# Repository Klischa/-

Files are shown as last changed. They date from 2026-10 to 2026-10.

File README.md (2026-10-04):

[README.md](https://github.com/user-attachments/files/33033183/README.md)
# Приводное / Опорно-ведущее колесо гусеницы «Муравей» z=24 (Шаг 50,5 мм)

Полный комплект конструкторской документации, файлов для ЧПУ резки и полноразмерных лекал (1:1) для приводной звездочки z=24 с трапециевидным зубом под гусеницу снегохода/буксировщика «Муравей».

---

## 1. Геометрические параметры венца z=24

- **Число зубьев ($z$):** 24
- **Шаг цевки ($p$):** 50,5 мм
- **Делительный диаметр ($d$):** 386,9 мм
- **Диаметр вершин ($d_a$):** 408,8 мм
- **Форма зуба:** Трапеция
  - Ширина плоской вершины: 6,97 мм
  - Радиусы скругления вершин: $R1,6 \pm 0,3$ мм
  - Угол наклона боковых граней (профиля): $20^\circ \pm 30'$
  - Радиус закругления впадин: $R3$ мм
- **Посадочные размеры ступицы (оригинал):**
  - Центральное отверстие: $\varnothing 75\text{ H7 } (+0,030)$ мм
  - Крепеж: 9 отверстий $\varnothing 9,5$ мм на диаметре $\varnothing 95$ мм (шаг $40^\circ$)
- **Толщина венца:** 10 мм
- **Материал:** СВМПЭ РЕ-1000 / Капролон ПА-6 / Сталь 09Г2С (толщина 10 мм)

---

## 2. Реализованные конструктивные решения

### Решение 1: Пакет с опорными боковыми катками (щеками)
- Звезда $z=24$ со стандартной высотой зуба ($d_f = 351,9$ мм, $h = 28,45$ мм).
- 2 опорные щеки $\varnothing 381,9$ мм толщиной по 19 мм (капролон / влагостойкая фанера ФСФ / Д16Т) с заходными фасками $3 \times 30^\circ$.
- Пакет стягивается 9 болтами М8×65. Общая ширина пакета **48 мм** (под 50-мм коридор клыков гусеницы «Муравей» с зазором по 1 мм на сторону).
- Скобы гусеницы опираются на гладкие щеки $\varnothing 381,9$ мм, исключая вибрацию и проваливание.

### Решение 2: Звездочка с опорным дном впадин ($d_f = 378,4$ мм)
- Одиночная звезда толщиной 10 мм без дополнительных катков.
- Дно впадины поднято до $d_f = 378,4$ мм ($h = 15,2$ мм), благодаря чему скобы гусеницы мягко ложатся на дно впадин.

---

## 3. Структура репозитория

```
├── README.md                                # Техническое описание проекта
├── drawings/                                # Конструкторские чертежи (ЕСКД/ГОСТ)
│   ├── sprocket_z24_support_drawing_A4.pdf  # Опорная звезда df=378.4 (1 лист А4)
│   ├── sprocket_z24_standard_drawing_A4.pdf # Приводная звезда df=351.9 (1 лист А4)
│   ├── cheek_d382_drawing_A4.pdf            # Щека опорная Ø381.9 (1 лист А4)
│   ├── assembly_wheel_drawing_A4.pdf        # Сборочный чертеж пакета 48 мм (1 лист А4)
│   └── all_four_a4_drawings_compiled.pdf    # Все 4 чертежа в едином файле для печати
├── cnc_dxf/                                 # Векторные чертежи для станков ЧПУ
│   ├── sprocket_z24_support_df378.dxf       # Контур опорной звезды df=378.4
│   ├── cheek_roller_d382.dxf                # Контур щеки Ø381.9
│   └── sprocket_muravey_z24_trapezoid.dxf   # Контур стандартной звезды df=351.9
├── templates_1to1/                          # Шаблоны 1:1 для распечатки и контроля
│   ├── sprocket_z24_support_sector_1to1.pdf # Сектор 6 зубьев df=378.4 на 1 лист А4
│   ├── sprocket_z24_support_1to1_tiled.pdf  # Полная звезда df=378.4 (7 листов А4)
│   ├── cheek_roller_d382_sector_1to1.pdf    # Сектор щеки Ø381.9 на 1 лист А4
│   └── sprocket_z24_sector_1to1.pdf         # Сектор стандартной звезды на 1 лист А4
└── scripts/                                 # Скрипты генерации геометрии (Python)
    └── render_complete_set_a4.py
```

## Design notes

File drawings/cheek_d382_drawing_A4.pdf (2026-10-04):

Б-Б (1:4)

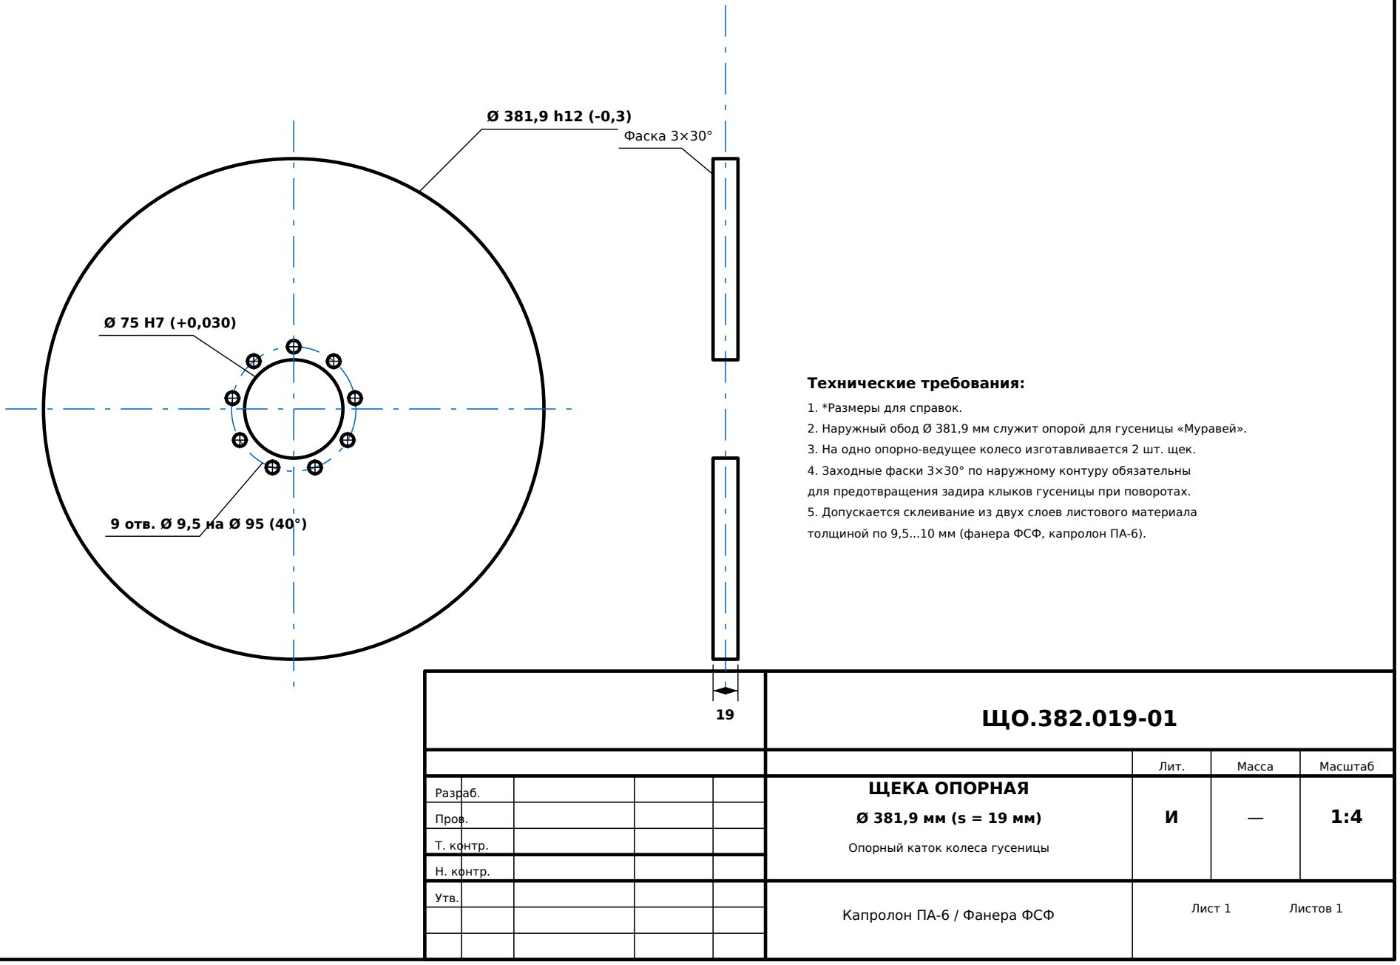
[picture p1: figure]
ЩЕКА ОПОРНАЯ; Опорный каток колеса гусеницы; Капролон ПА-6 / Фанера ФСФ; Лит.; Масса; Масштаб; Лист 1; Листов 1; Разраб.; Пров.; Т. контр.; Н. контр.; Утв.; 9 отв. Ø 9,5 на Ø 95 (40°); Фаска 3×30°; Технические требования:; 1. *Размеры для справок.

2. Наружный обод Ø 381,9 мм служит опорой для гусеницы «Муравей».
3. На одно опорно-ведущее колесо изготавливается 2 шт. щек.
4. Заходные фаски 3×30° по наружному контуру обязательны
для предотвращения задира клыков гусеницы при поворотах.
5. Допускается склеивание из двух слоев листового материала толщиной по 9,5...10 мм (фанера ФСФ, капролон ПА-6).

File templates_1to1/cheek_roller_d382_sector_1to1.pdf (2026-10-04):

# ШАБЛОН-СЕКТОР БОКОВОЙ ОПОРНОЙ ЩЕКИ Ø 381.9 мм — 1:1

## Опорный каток под резиновую дорожку гусеницы «Муравей» (2 шт. на 1 колесо, толщина 19 мм)

ЦЕНТР ЩЕКИ (0,0)

ЛУЧ 60° (ЛИНИЯ РАЗМЕТКИ) | ЛУЧ 60°

## НАРУЖНЫЙ ОПОРНЫЙ ОБОД Ø 381.9 мм (ПОД ПОЛОТНО ГУСЕНИЦЫ)

## КАК ИЗГОТОВИТЬ ОПОРНУЮ ЩЕКУ ПО ДАННОМУ ШАБЛОНУ:

- Требуется 2 щеки на одно колесо. Толщина каждой щеки 18...19 мм (или склеить из двух слоев по 9.5-10 мм).
- Разметка: закрепить центр (0,0) в заготовке, очертить дугу 60°, повернуть 6 раз -> замкнутый круг Ø381.9 мм.
- Просверлить центр Ø 75 мм и 9 отверстий Ø 9.5 мм на Ø 95 мм (совпадают со звездой).
- По наружной кромке снять фаску 3×30° для легкого центрирования между клыками гусеницы.
0 мм | 10 | 20 | 30 | 40 | 50 | 60 | 70 | 80 | 90 | 100

КОНТРОЛЬНАЯ ШКАЛА 100 мм (ПРОВЕРКА МАСШТАБА 1:1)

Масштаб 1:1 (100%)

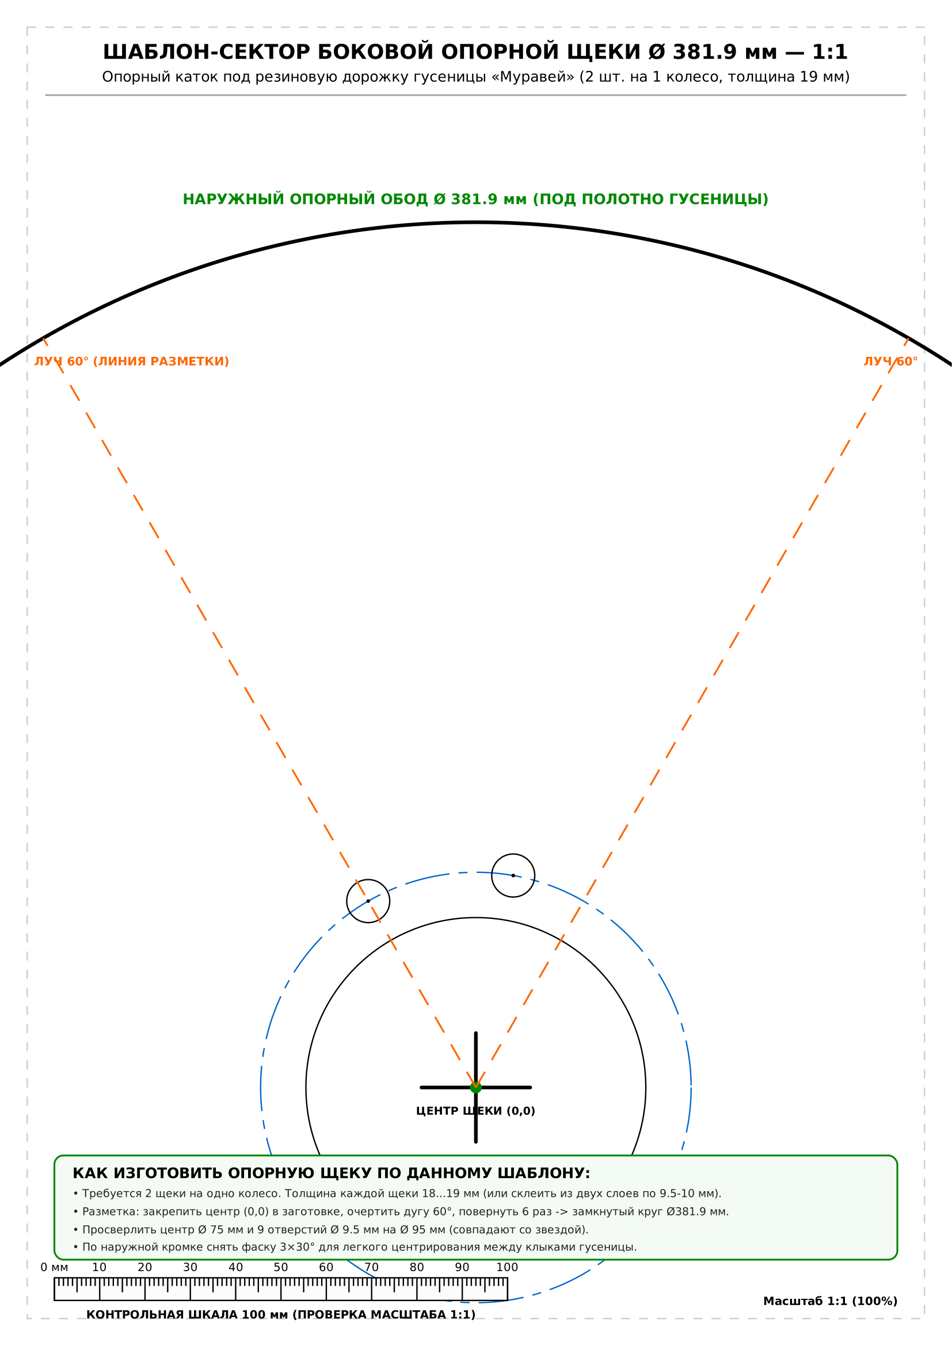
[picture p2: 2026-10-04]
templates_1to1/cheek_roller_d382_sector_1to1.png

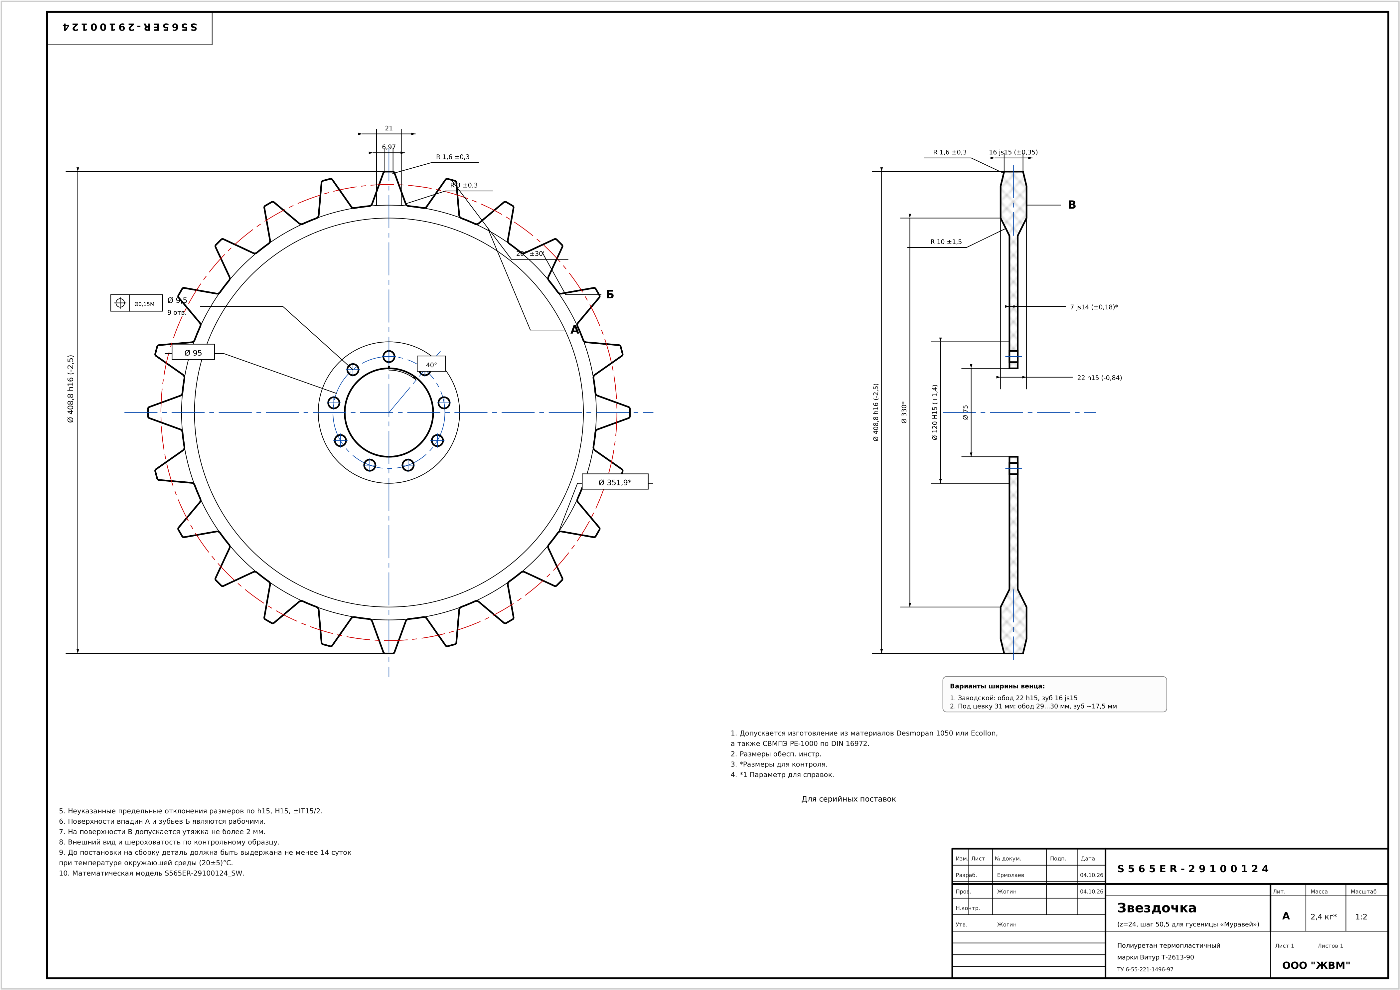
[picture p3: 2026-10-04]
drawings/sprocket_z24_support_df378.png

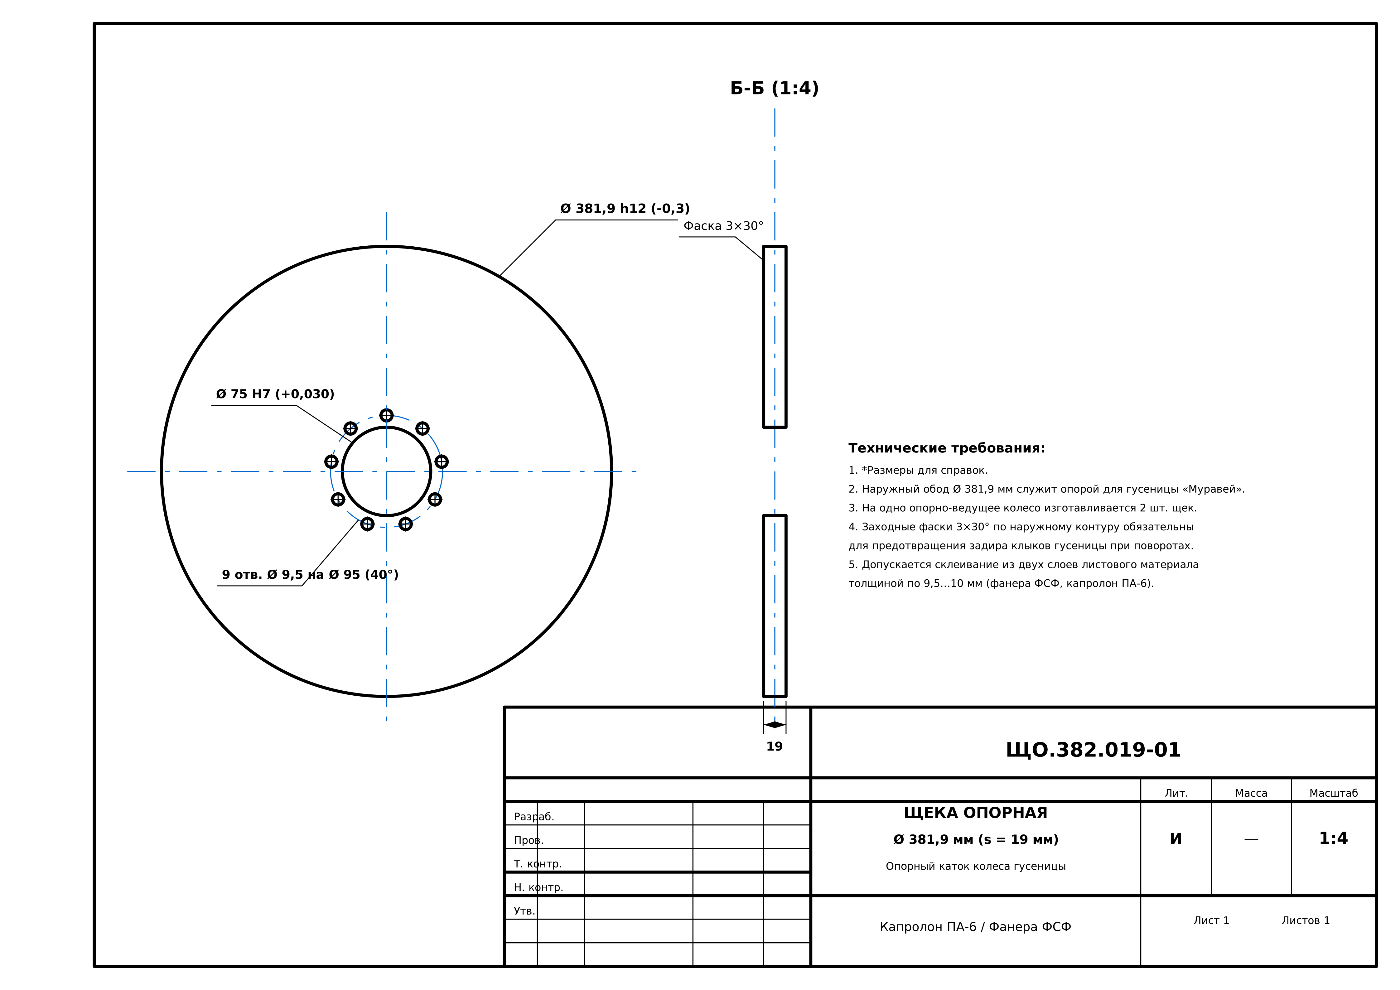
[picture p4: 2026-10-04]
drawings/cheek_d382_drawing_A4.png

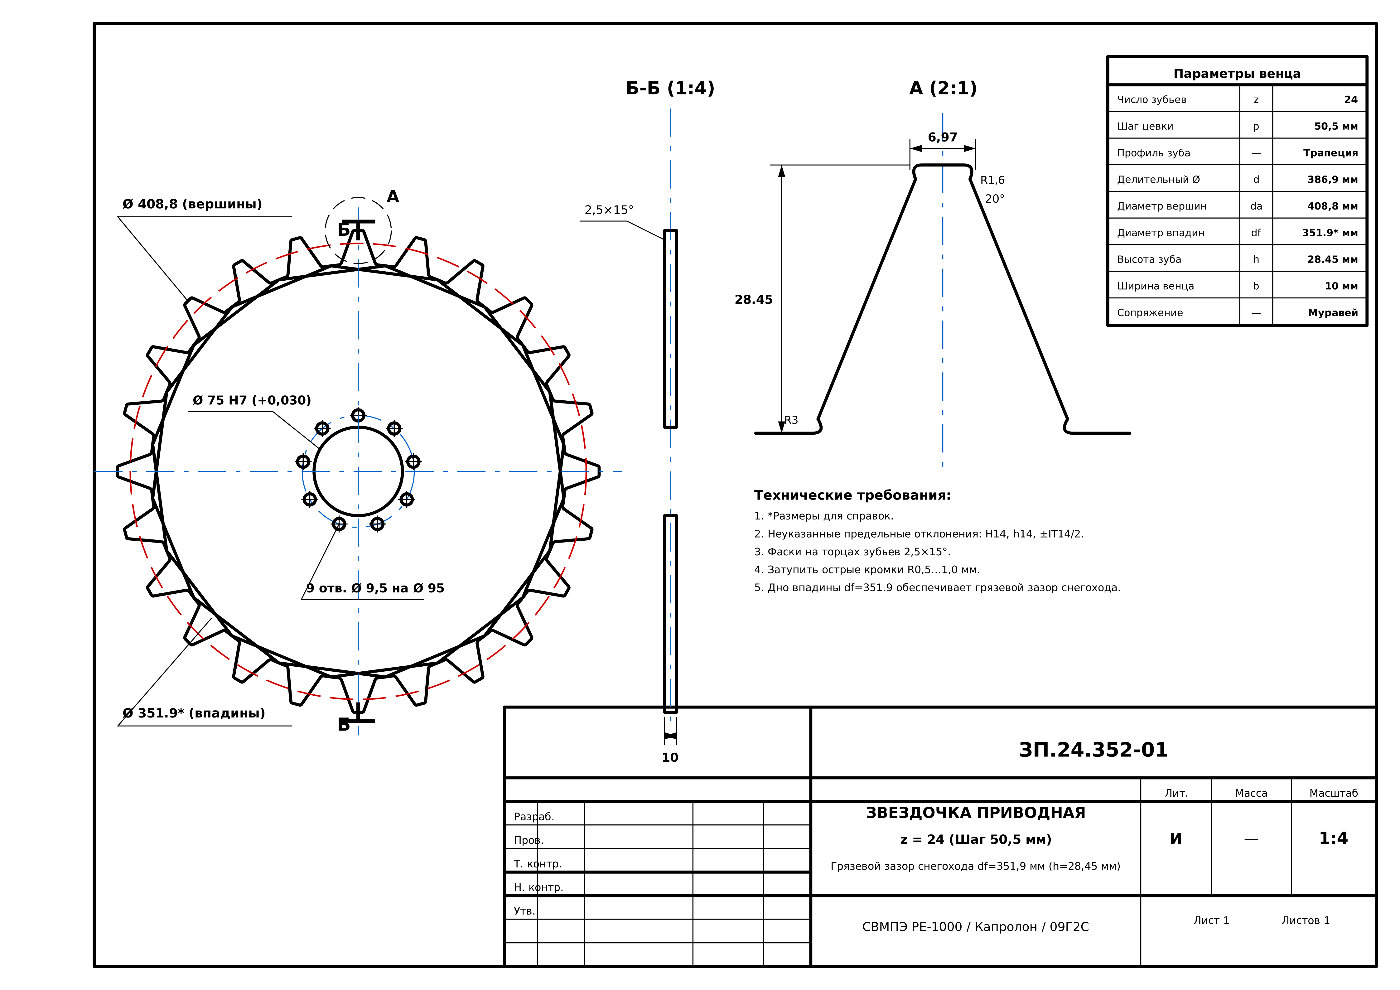
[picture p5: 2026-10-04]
drawings/sprocket_z24_standard_drawing_A4.png

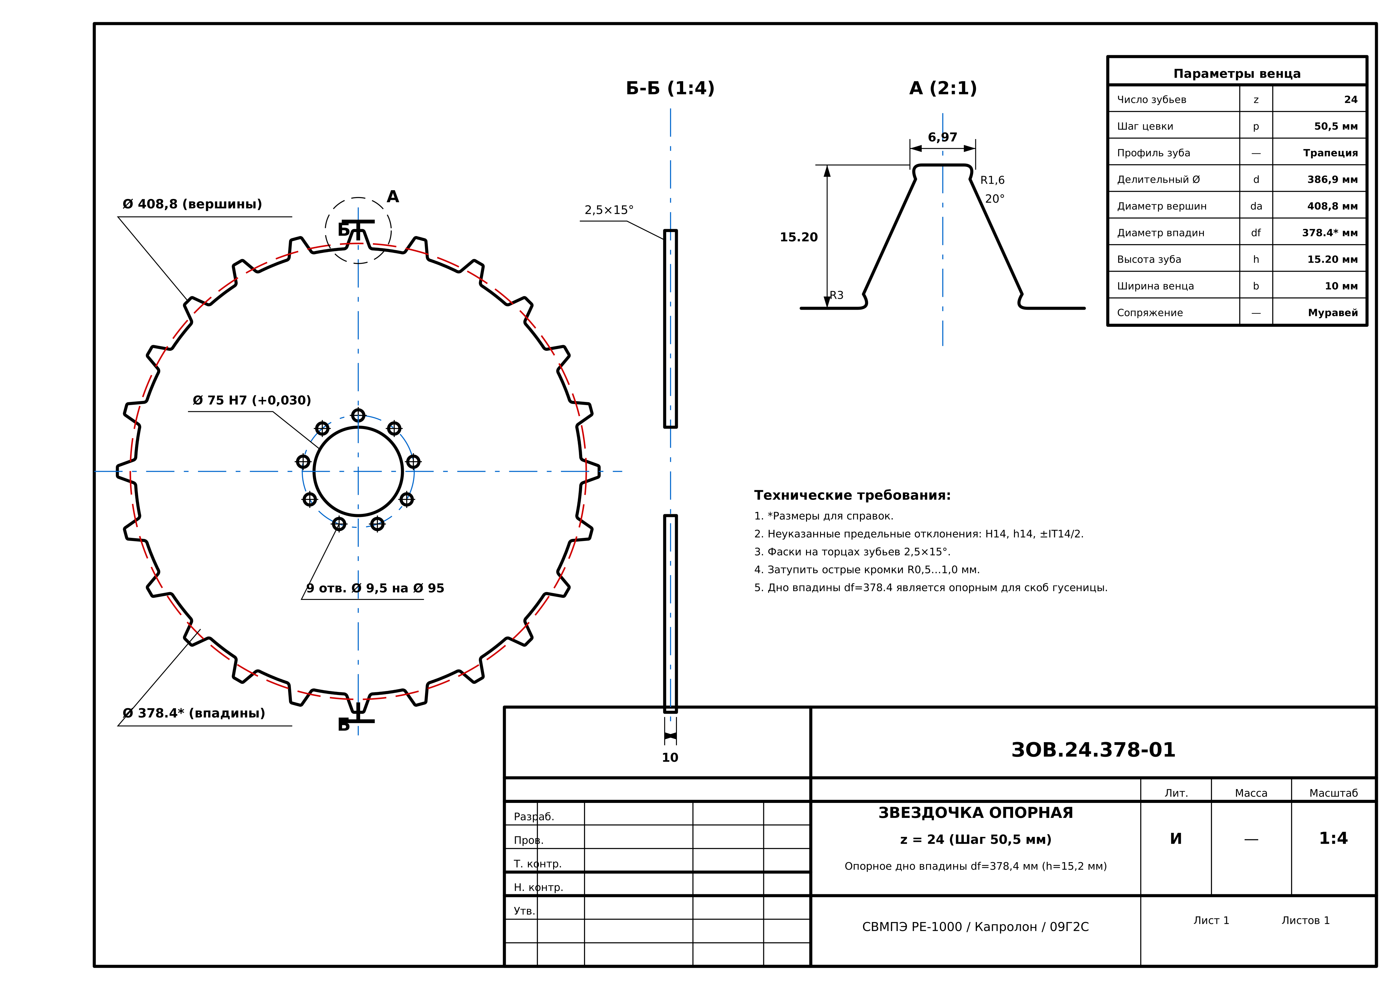
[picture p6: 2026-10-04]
drawings/sprocket_z24_support_drawing_A4.png

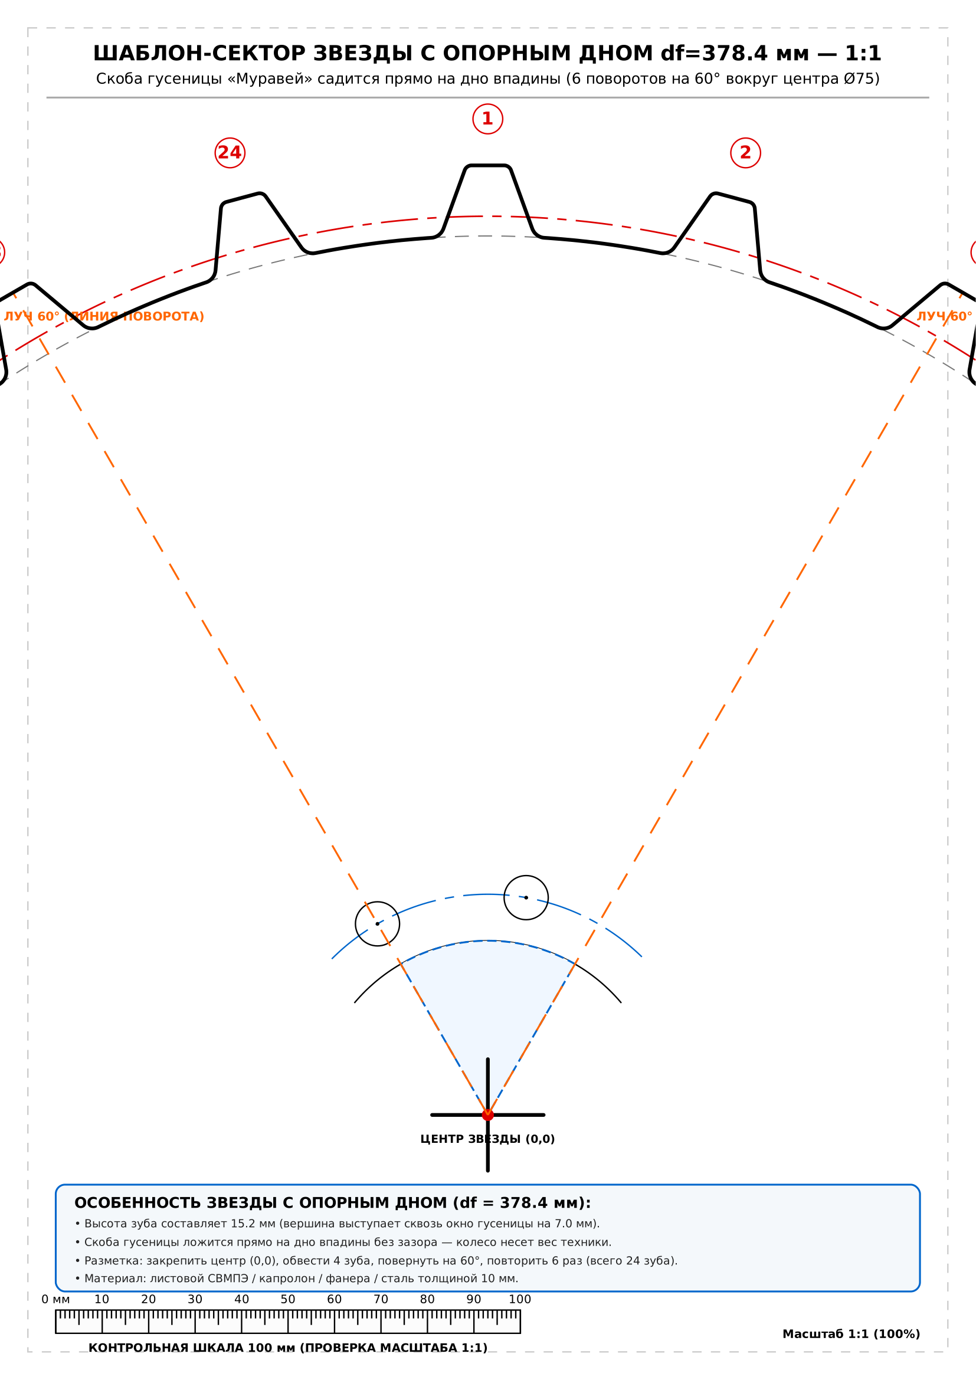
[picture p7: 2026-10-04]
templates_1to1/sprocket_z24_support_sector_1to1.png

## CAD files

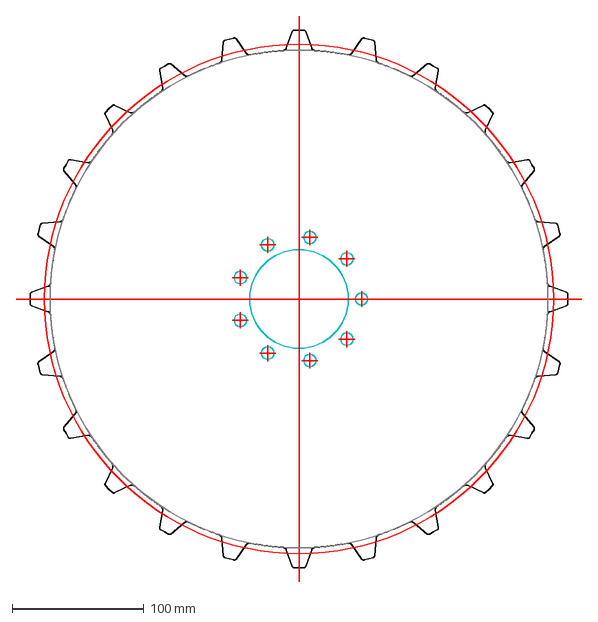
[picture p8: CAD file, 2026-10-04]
cnc_dxf/sprocket_z24_support_df378.dxf
430.0 x 430.0 mm

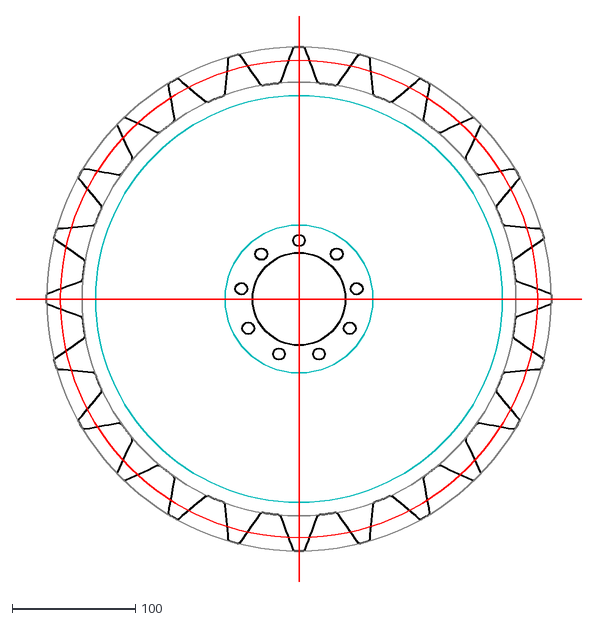
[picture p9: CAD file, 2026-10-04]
cnc_dxf/sprocket_muravey_z24_trapezoid.dxf
458.8 x 458.8

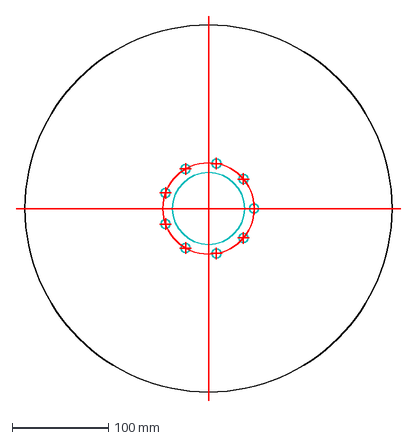
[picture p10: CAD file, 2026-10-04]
cnc_dxf/cheek_roller_d382.dxf
400.0 x 400.0 mm

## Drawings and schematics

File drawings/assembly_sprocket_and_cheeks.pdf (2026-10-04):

0

20

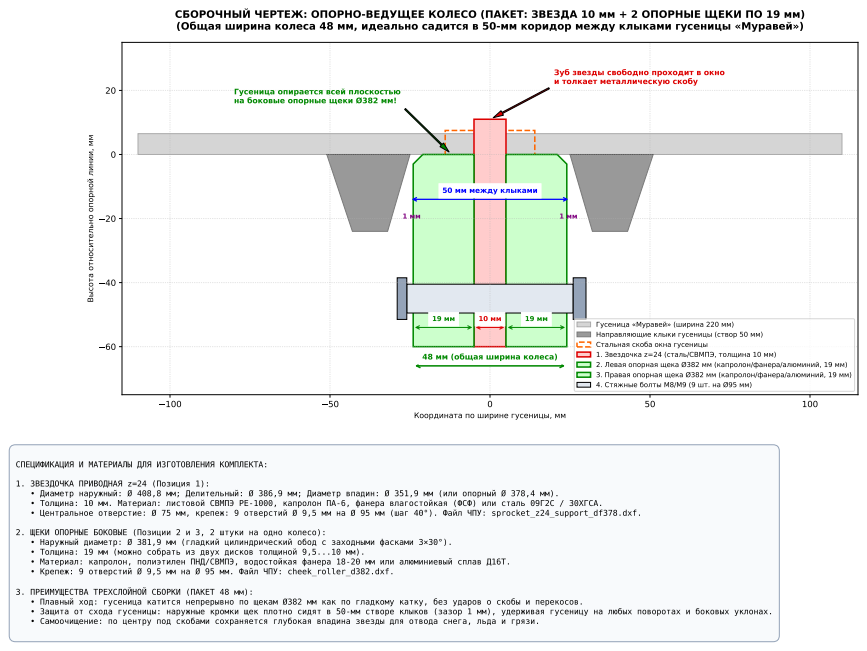
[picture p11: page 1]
: sprocket_z24_support_df378.dxf.; : cheek_roller_d382.dxf.

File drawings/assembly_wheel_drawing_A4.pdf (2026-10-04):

1
2

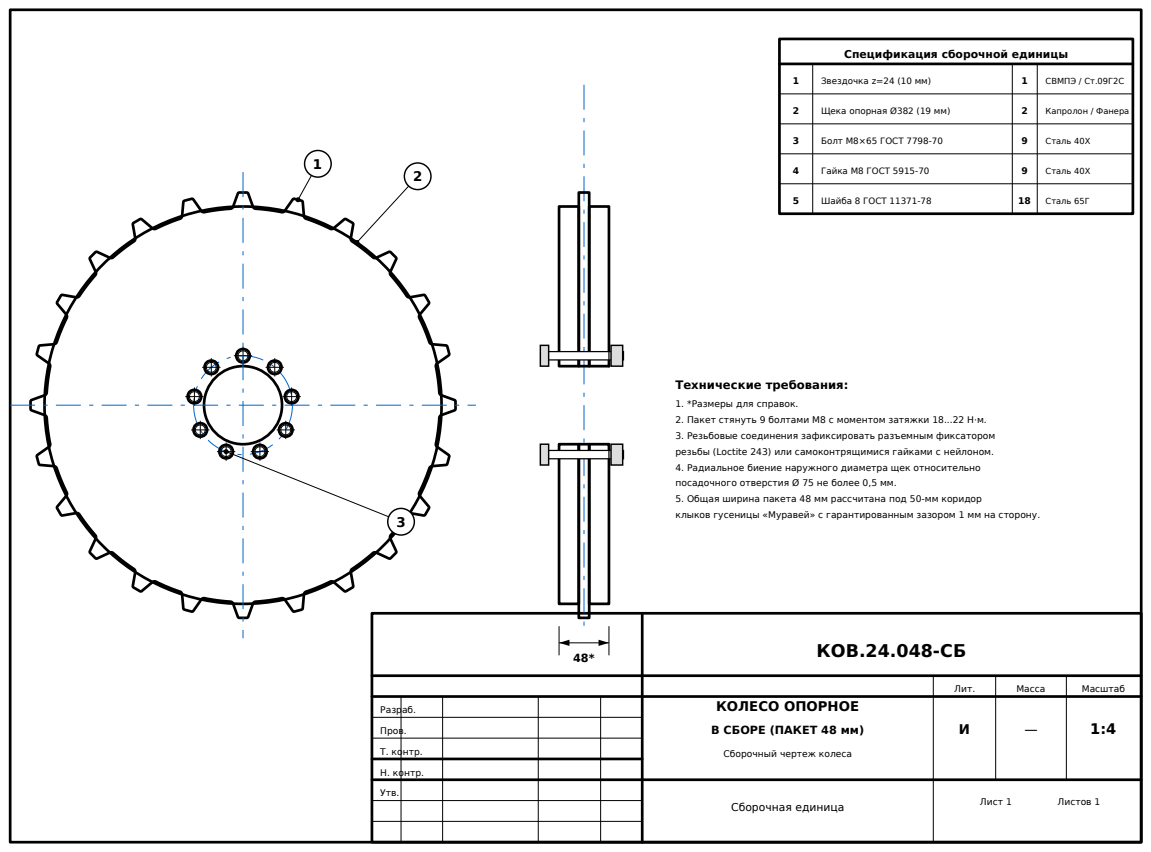
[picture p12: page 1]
КОВ.24.048-СБ; Сборочная единица; Лит.; Масса; Масштаб; Лист 1; Листов 1; Разраб.; Пров.; Т. контр.; Н. контр.; Утв.; Звездочка z=24 (10 мм); СВМПЭ / Ст.09Г2С; Щека опорная Ø382 (19 мм); Капролон / Фанера; Болт М8×65 ГОСТ 7798-70; Сталь 40Х; Гайка М8 ГОСТ 5915-70; Шайба 8 ГОСТ 11371-78; Сталь 65Г; Технические требования:

Спецификация сборочной единицы

1. *Размеры для справок.
2. Пакет стянуть 9 болтами М8 с моментом затяжки 18...22 Н·м.
3. Резьбовые соединения зафиксировать разъемным фиксатором
резьбы (Loctite 243) или самоконтрящимися гайками с нейлоном.
4. Радиальное биение наружного диаметра щек относительно
посадочного отверстия Ø 75 не более 0,5 мм.
5. Общая ширина пакета 48 мм рассчитана под 50-мм коридор
клыков гусеницы «Муравей» с гарантированным зазором 1 мм на сторону.

КОЛЕСО ОПОРНОЕ
В СБОРЕ (ПАКЕТ 48 мм)

Сборочный чертеж колеса

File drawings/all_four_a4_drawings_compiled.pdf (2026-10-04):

A
Б

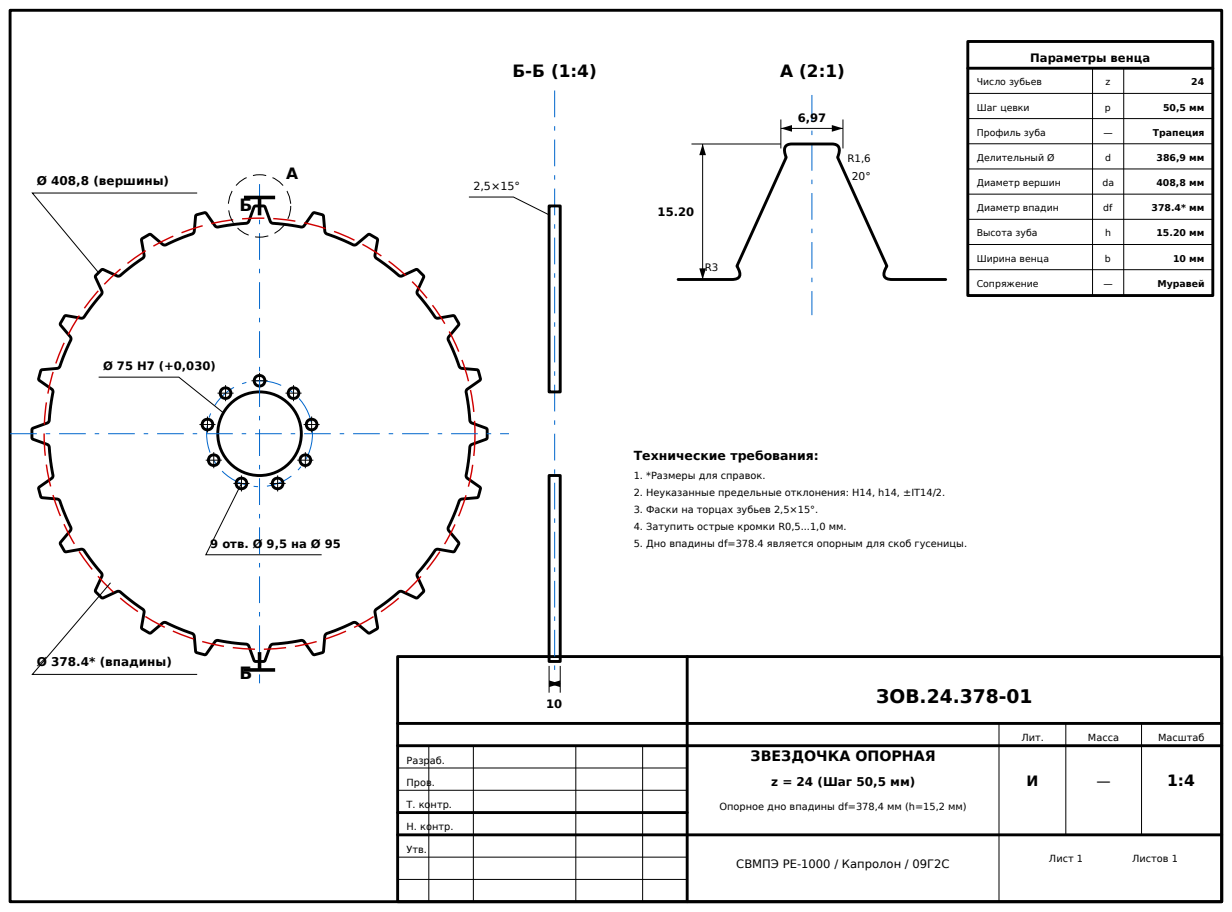
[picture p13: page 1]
ЗОВ.24.378-01; ЗВЕЗДОЧКА ОПОРНАЯ; z = 24 (Шаг 50,5 мм); Лит.; Масса; Масштаб; Лист 1; Листов 1; Разраб.; Пров.; Т. контр.; Н. контр.; Утв.; Ø 408,8 (вершины); Ø 378.4* (впадины); 9 отв. Ø 9,5 на Ø 95; Параметры венца; Число зубьев; Шаг цевки; Профиль зуба; Трапеция; Делительный Ø; Диаметр вершин; Диаметр впадин; Высота зуба; Ширина венца; Сопряжение; Муравей

Технические требования:
1. *Размеры для справок.
2. Неуказанные предельные отклонения: H14, h14, ±IT14/2.
3. Фаски на торцах зубьев 2,5×15°.
4. Затупить острые кромки R0,5...1,0 мм.
5. Дно впадины df=378.4 является опорным для скоб гусеницы.

Опорное дно впадины df=378,4 мм (h=15,2 мм)

СВМПЭ РЕ-1000 / Капролон / 09Г2С

A
Б

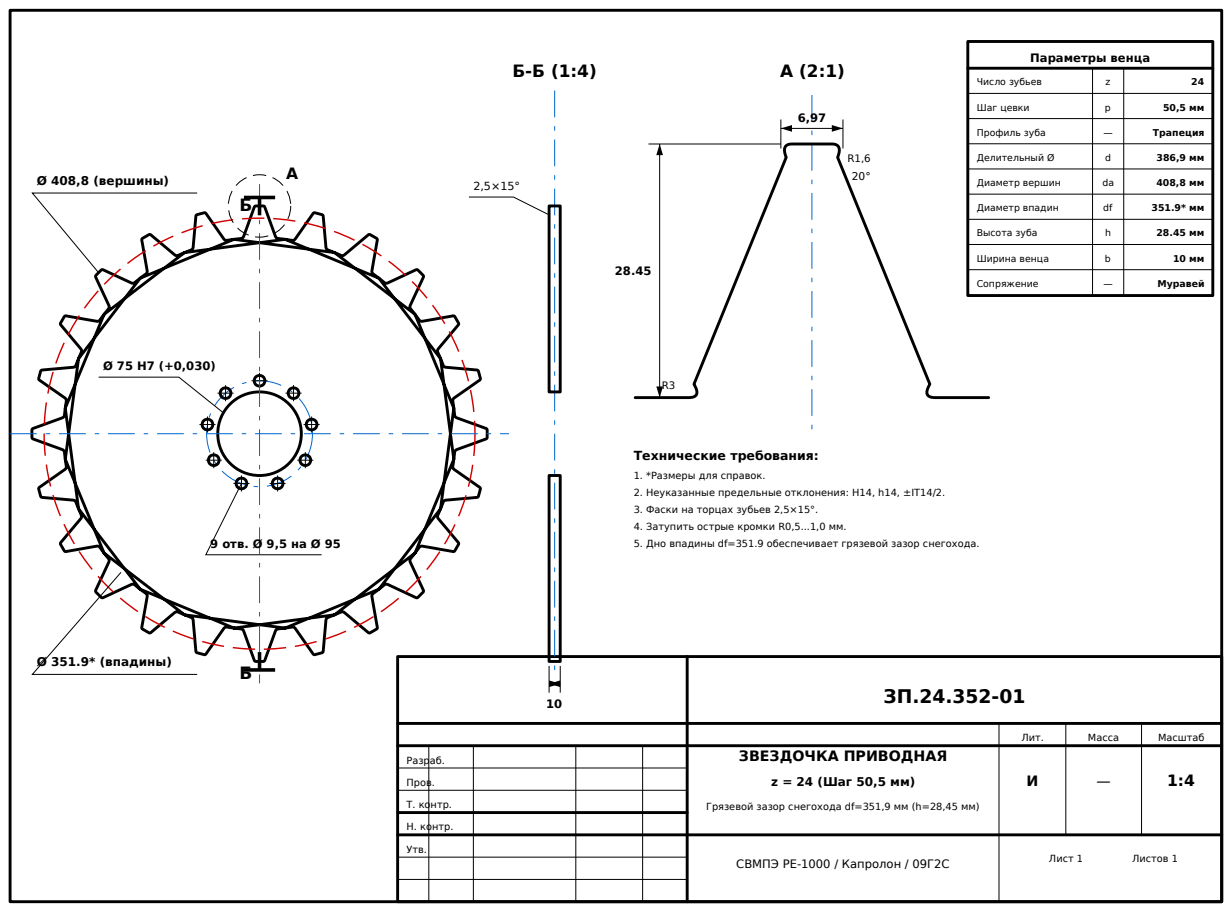
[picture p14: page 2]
ЗВЕЗДОЧКА ПРИВОДНАЯ; z = 24 (Шаг 50,5 мм); Лит.; Масса; Масштаб; Разраб.; Пров.; Т. контр.; Н. контр.; Ø 408,8 (вершины); Ø 351.9* (впадины); 9 отв. Ø 9,5 на Ø 95; Параметры венца; Число зубьев; Шаг цевки; Профиль зуба; Трапеция; Делительный Ø; Диаметр вершин; Диаметр впадин; Высота зуба; Ширина венца; Сопряжение; Муравей

Технические требования:
1. *Размеры для справок.
2. Неуказанные предельные отклонения: H14, h14, ±IT14/2.
3. Фаски на торцах зубьев 2,5×15°.
4. Затупить острые кромки R0,5...1,0 мм.
5. Дно впадины df=351.9 обеспечивает грязевой зазор снегохода.

Грязевой зазор снегохода df=351,9 мм (h=28,45 мм)

СВМПЭ РЕ-1000 / Капролон / 09Г2С

Б-Б (1:4)

ЩЕКА ОПОРНАЯ; Опорный каток колеса гусеницы; Капролон ПА-6 / Фанера ФСФ; Лит.; Масса; Масштаб; Разраб.; Пров.; Т. контр.; Н. контр.; 9 отв. Ø 9,5 на Ø 95 (40°); Фаска 3×30°; Технические требования:; 1. *Размеры для справок.

2. Наружный обод Ø 381,9 мм служит опорой для гусеницы «Муравей».
3. На одно опорно-ведущее колесо изготавливается 2 шт. щек.
4. Заходные фаски 3×30° по наружному контуру обязательны
для предотвращения задира клыков гусеницы при поворотах.
5. Допускается склеивание из двух слоев листового материала толщиной по 9,5...10 мм (фанера ФСФ, капролон ПА-6).

1
2

КОВ.24.048-СБ; Сборочная единица; Лит.; Масса; Масштаб; Разраб.; Пров.; Т. контр.; Н. контр.; Звездочка z=24 (10 мм); СВМПЭ / Ст.09Г2С; Щека опорная Ø382 (19 мм); Капролон / Фанера; Болт М8×65 ГОСТ 7798-70; Сталь 40Х; Гайка М8 ГОСТ 5915-70; Шайба 8 ГОСТ 11371-78; Сталь 65Г; Технические требования:

Спецификация сборочной единицы

1. *Размеры для справок.
2. Пакет стянуть 9 болтами М8 с моментом затяжки 18...22 Н·м.
3. Резьбовые соединения зафиксировать разъемным фиксатором
резьбы (Loctite 243) или самоконтрящимися гайками с нейлоном.
4. Радиальное биение наружного диаметра щек относительно
посадочного отверстия Ø 75 не более 0,5 мм.
5. Общая ширина пакета 48 мм рассчитана под 50-мм коридор
клыков гусеницы «Муравей» с гарантированным зазором 1 мм на сторону.

КОЛЕСО ОПОРНОЕ
В СБОРЕ (ПАКЕТ 48 мм)

Сборочный чертеж колеса

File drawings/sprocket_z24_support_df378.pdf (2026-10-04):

В

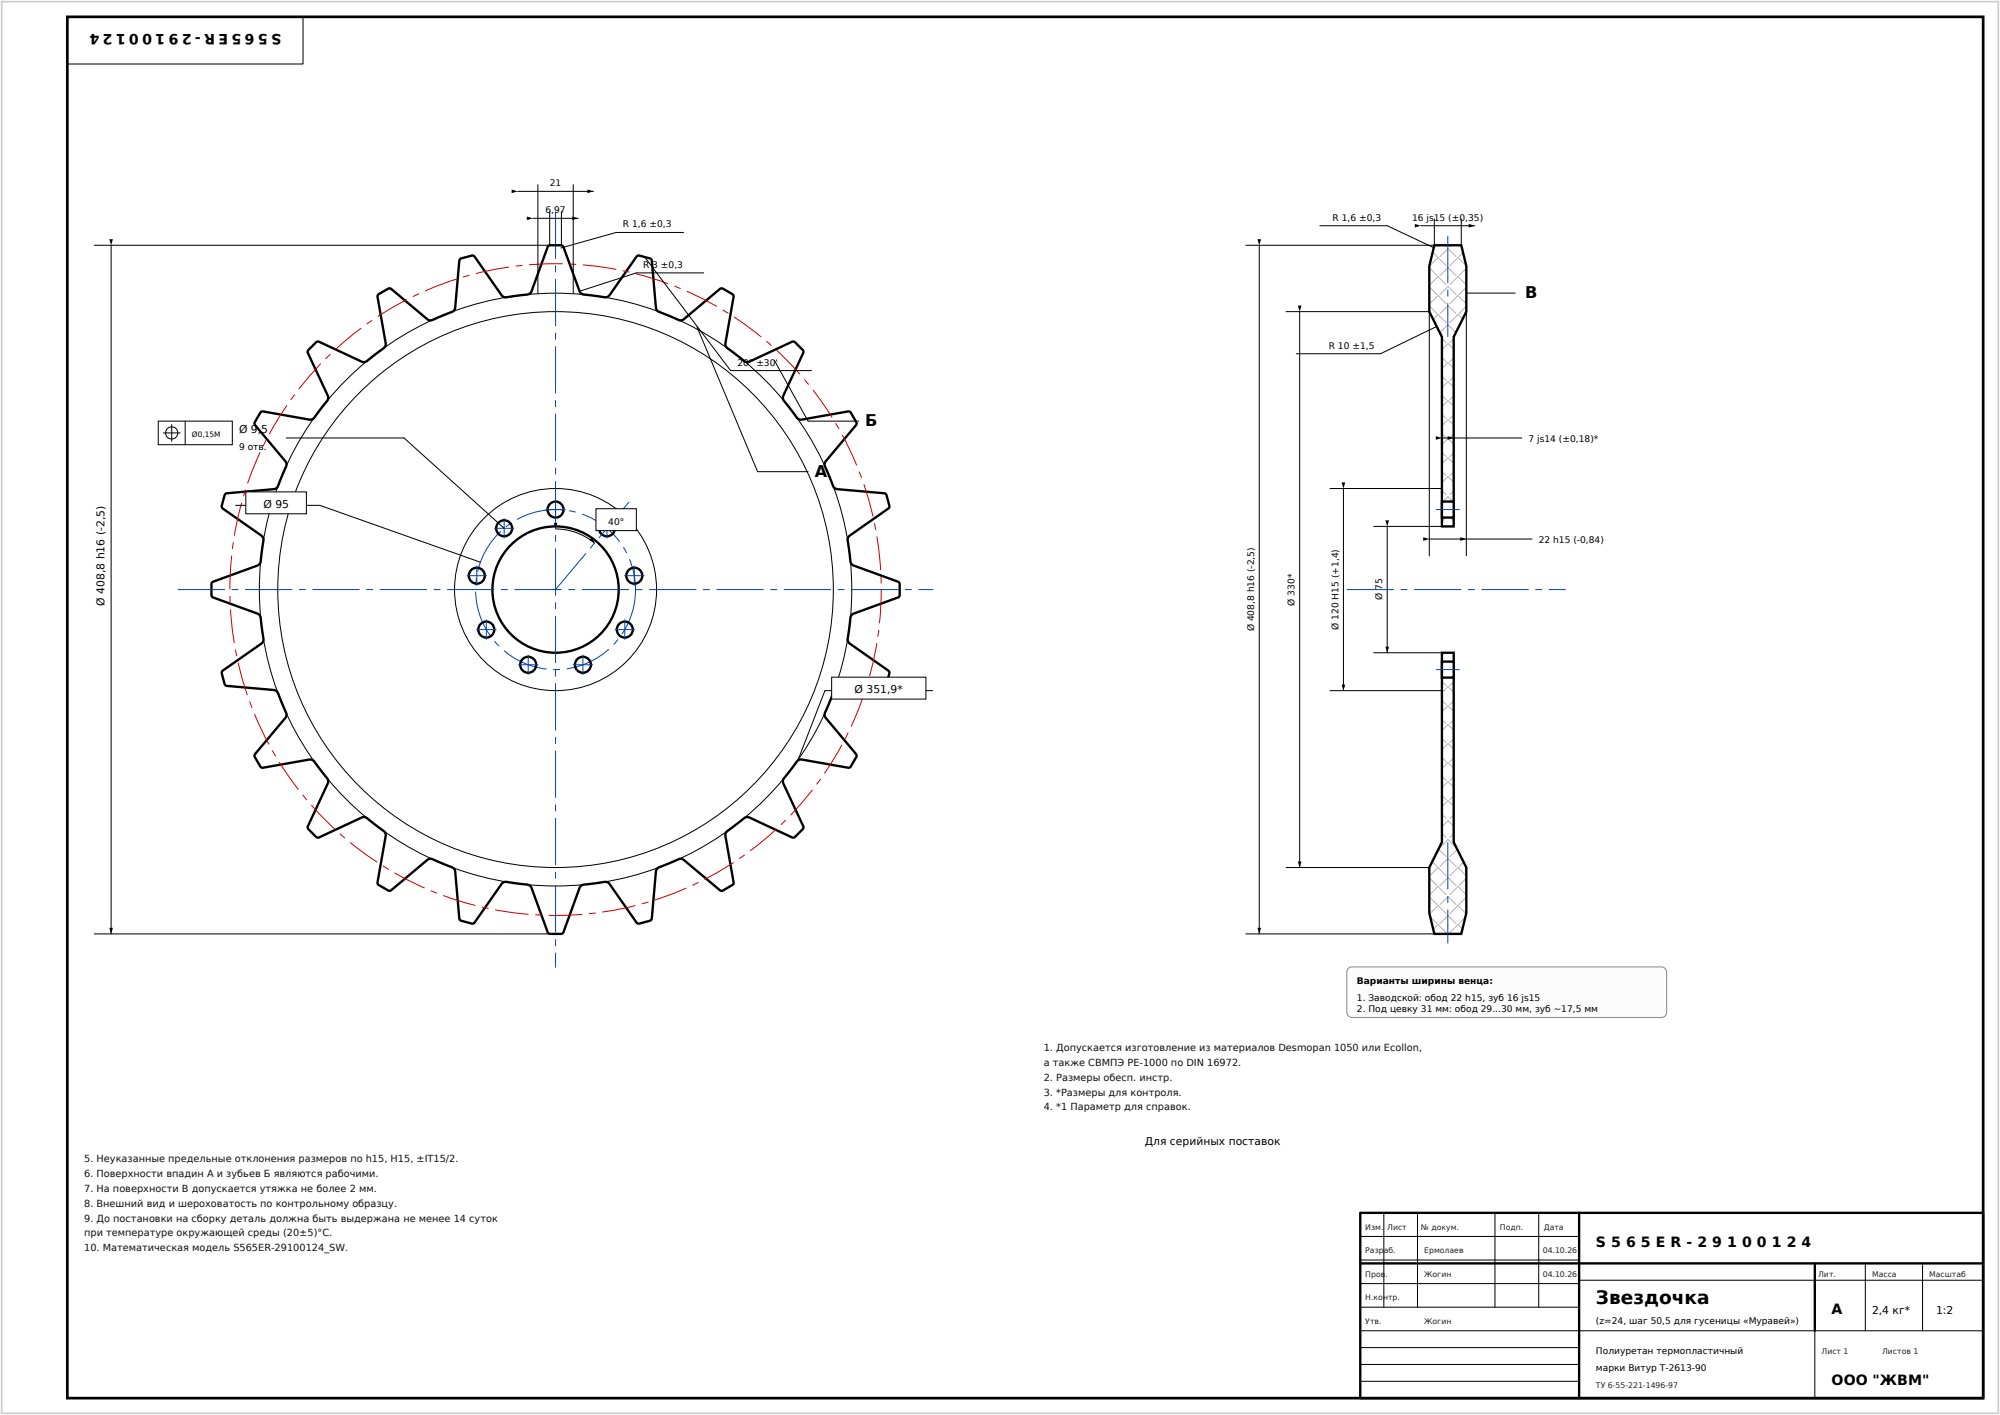
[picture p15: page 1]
Изм.; Лист; № докум.; Подп.; Дата; Разраб.; Ермолаев; Пров.; Жогин; Н.контр.; Утв.; Звездочка; Полиуретан термопластичный; марки Витур Т-2613-90; Лит.; Масса; Масштаб; Лист 1; Листов 1; ООО "ЖВМ"; 9 отв.

Варианты ширины венца:
1. Заводской: обод 22 h15, зуб 16 js15
2. Под цевку 31 мм: обод 29...30 мм, зуб ~17,5 мм

1. Допускается изготовление из материалов Desmopan 1050 или Ecollon,
а также СВМПЭ PE-1000 по DIN 16972.
2. Размеры обесп. инстр.
3. *Размеры для контроля.
4. *1 Параметр для справок.

Для серийных поставок

5. Неуказанные предельные отклонения размеров по h15, H15, ±IT15/2.
6. Поверхности впадин А и зубьев Б являются рабочими.
7. На поверхности В допускается утяжка не более 2 мм.
8. Внешний вид и шероховатость по контрольному образцу.
9. До постановки на сборку деталь должна быть выдержана не менее 14 суток
при температуре окружающей среды (20±5)°C.
10. Математическая модель S565ER-29100124_SW.

(z=24, шаг 50,5 для гусеницы «Муравей»)

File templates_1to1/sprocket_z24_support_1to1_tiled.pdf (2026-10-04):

# ОН ЗВЕЗДОЧКИ z=24 С ОПОРНЫМ ДНОМ (df=378.4 мм) (ШАГ 50,5 мм) ДЛЯ ПЕЧА

## Гусеница «Муравей» / Зацепление через окна / Трапецеидальный зуб

## СХЕМА РАСКЛАДКИ 6 ЛИСТОВ ФОРМАТА А4 (СЕТКА 3 × 2):

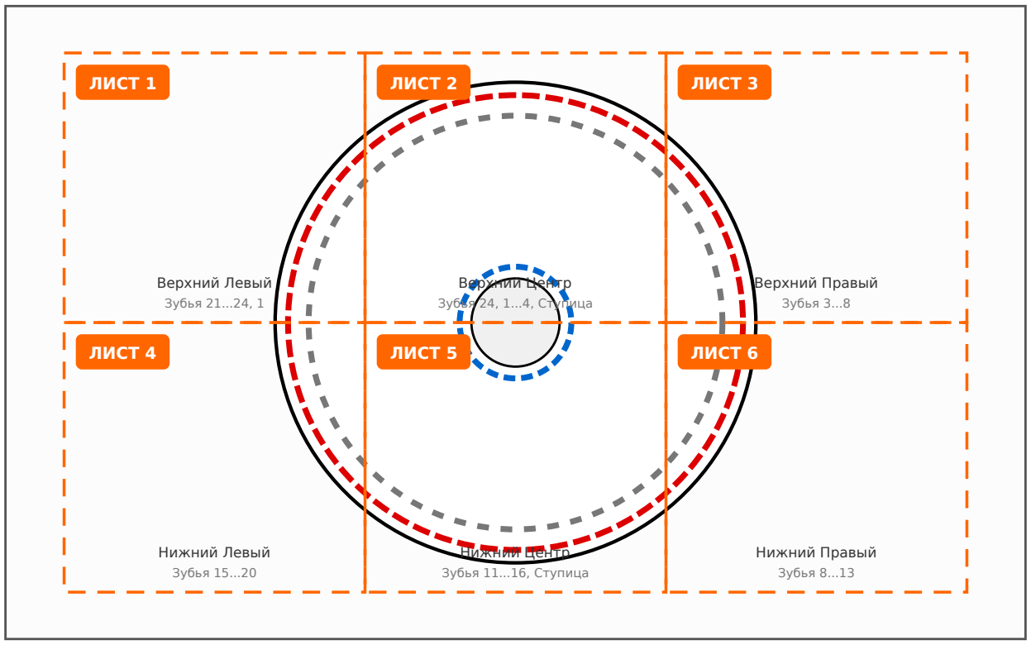
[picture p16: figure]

ЛИСТ 1 Верхний Левый Зубья 21...24, 1 | ЛИСТ 2 Верхний Центр Зубья 24, 1...4, Ступица | ЛИСТ 3 Верхний Правый Зубья 3...8
ЛИСТ 4 Нижний Левый Зубья 15...20 | ЛИСТ 5 Нижний Центр Зубья 11...16, Ступица | ЛИСТ 6 Нижний Правый Зубья 8...13

## КОНТРОЛЬНЫЕ ГЕОМЕТРИЧЕСКИЕ РАЗМЕРЫ (МАСШТАБ 1:1):

- Наружный диаметр (по вершинам): Ø 408,8 мм
- Диаметр впадин (дно зубьев): Ø 378,4 мм (ОПОРНЫЙ)
- Делительный диаметр зацепления: Ø 386,9 мм
- Посадочное отверстие под вал: Ø 75,0 мм
- Крепежные отв. (9 шт.): | Ø 9,5 мм на Ø 95 мм
- Ширина вершины / основания: 6,97 мм / 21,0 мм

# ПОШАГОВАЯ ИНСТРУКЦИЯ ПО ПЕЧАТИ И СКЛЕЙКЕ:

### 1. НАСТРОЙКА ПРИНТЕРА:

В программе просмотра PDF (Acrobat Reader, браузер) в окне печати выберите масштаб ровно «100%» или «Реальный разме р» (Actual size). НЕ ВЫБИРАЙТЕ «Подогнать под размер страницы» (Fit to page)!

### 2. ПРОВЕРКА МАСШТАБА:

Внизу каждого листа напечатана контрольная шкала 100 мм. После печати приложите линейку к шкале: расстояние от 0 до 100 мм должно составлять ровно 100,0 мм.

### 3. ОБРЕЗКА ПОЛЕЙ:

На каждом листе оранжевым пунктиром нанесена «Линия склейки». Отрежьте бумагу канцелярским ножом по линейке строго по этой пунктирной линии со стороны наложения.

### 4. СОВМЕЩЕНИЕ ЛИСТОВ:

Наложите листы срезанным краем на соседний лист так, чтобы совпали кресты совмещения ⨁, контуры зубьев и красная де лительная окружность. Проверьте совпадение на просвет (на окне или световом столе).

### 5. ФИКСАЦИЯ:

Скрепите совмещенные листы малярным скотчем с обратной стороны или клеящим карандашом.

### 6. ПЕРЕНОС НА МАТЕРИАЛ:

Наклейте готовый шаблон на заготовку (СВМПЭ PE-1000, капролон или фанеру/металл) клеем-спреем или зафиксируйте по ц ентру Ø75 мм. Вырезайте точно по сплошной черной линии.

0 мм | 10 | 20 | 30 | 40 | 50 | 60 | 70 | 80 | 90 | 100

КОНТРОЛЬНАЯ ШКАЛА 100 мм (ПРОВЕРКА МАСШТАБА 1:1)

Лист 1 из 7 (Общая инструкция)

Далее следуют Листы 1..6 шаблона 1:1

# ЗВЕЗДОЧКА ОПОРНАЯ df=378.4 мм (Шаг 50,5 мм, z=24) — 1:1

Лист 1 из 6 [Ряд 1, Верхний Левый] | Печатать при 100% («Реальный размер»)

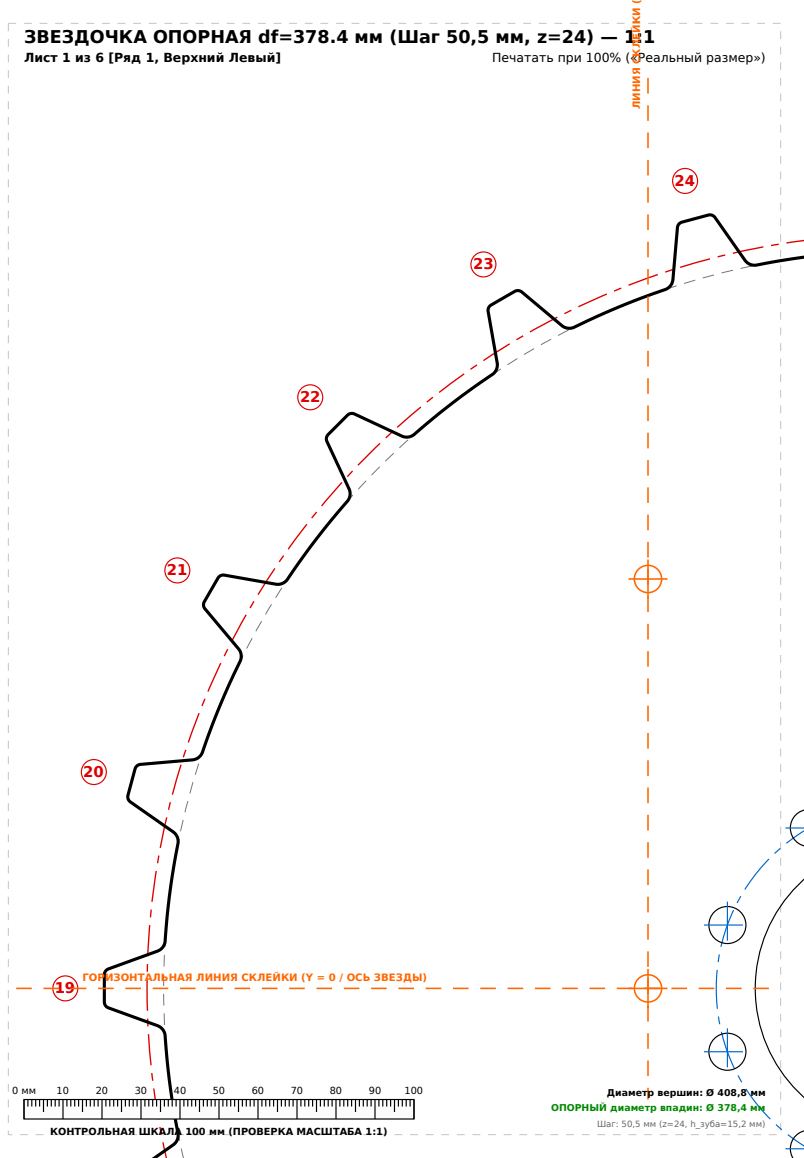
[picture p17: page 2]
ЛИНИЯ СКЛЕЙКИ (

ГОРИЗОНТАЛЬНАЯ ЛИНИЯ СКЛЕЙКИ (Y = 0 / ОСЬ ЗВЕЗДЫ)

Диаметр вершин: Ø 408,8 мм

ОПОРНЫЙ диаметр впадин: Ø 378,4 мм

Шаг: 50,5 мм (z=24, h_зуба=15,2 мм)

Лист 2 из 6 [Ряд 1, Верхний Центр] | Печатать при 100% («Реальный размер»)

1

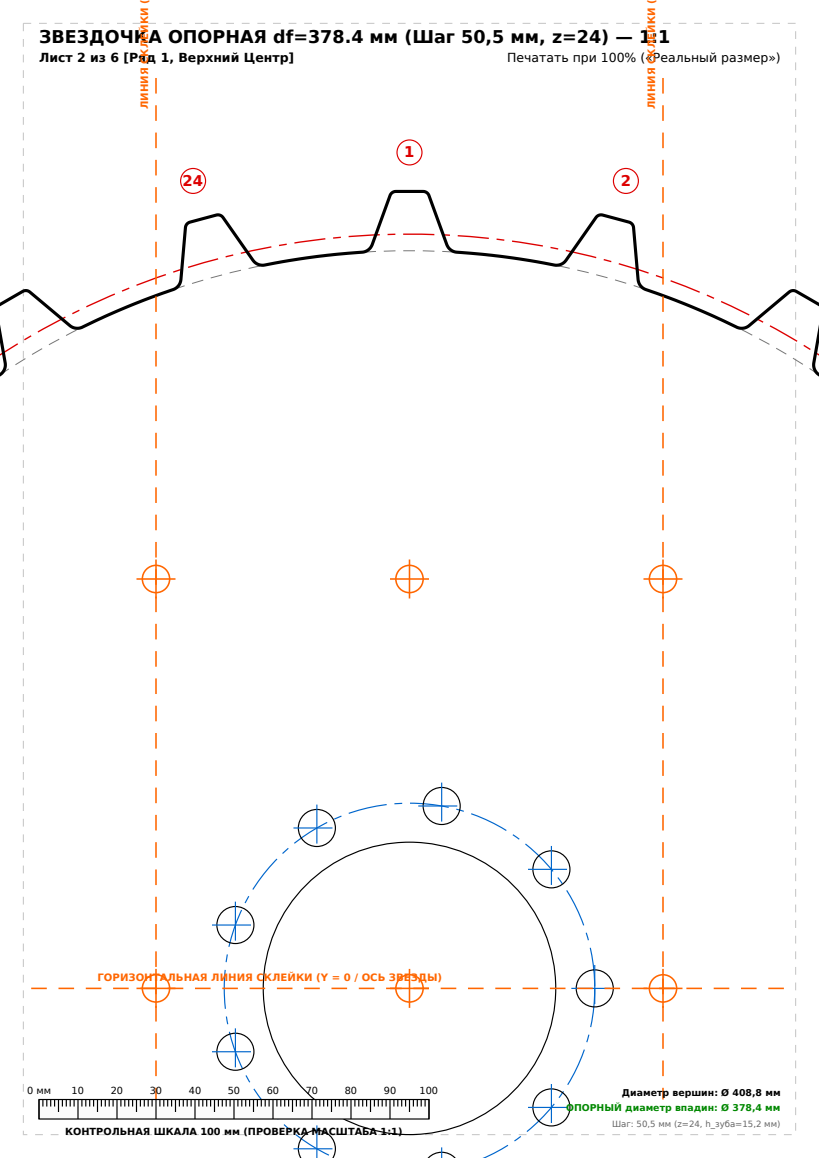
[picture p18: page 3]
ЛИНИЯ СКЛЕЙКИ (

ГОРИЗОНТАЛЬНАЯ ЛИНИЯ СКЛЕЙКИ (Y = 0 / ОСЬ ЗВЕЗДЫ)

Лист 3 из 6 [Ряд 1, Верхний Правый] | Печатать при 100% («Реальный размер»)

2

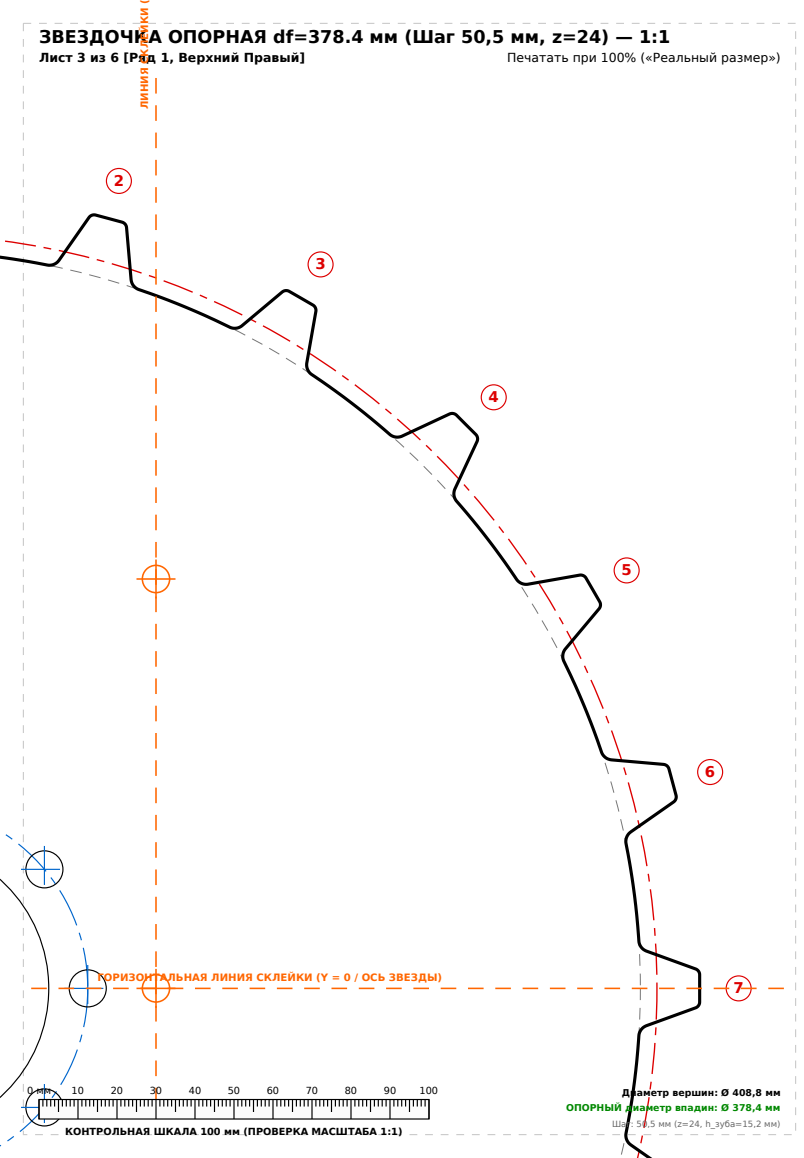
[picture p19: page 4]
ЛИНИЯ СКЛЕЙКИ (

ГОРИЗОНТАЛЬНАЯ ЛИНИЯ СКЛЕЙКИ (Y = 0 / ОСЬ ЗВЕЗДЫ)

Лист 4 из 6 [Ряд 2, Нижний Левый] | Печатать при 100% («Реальный размер»)

19

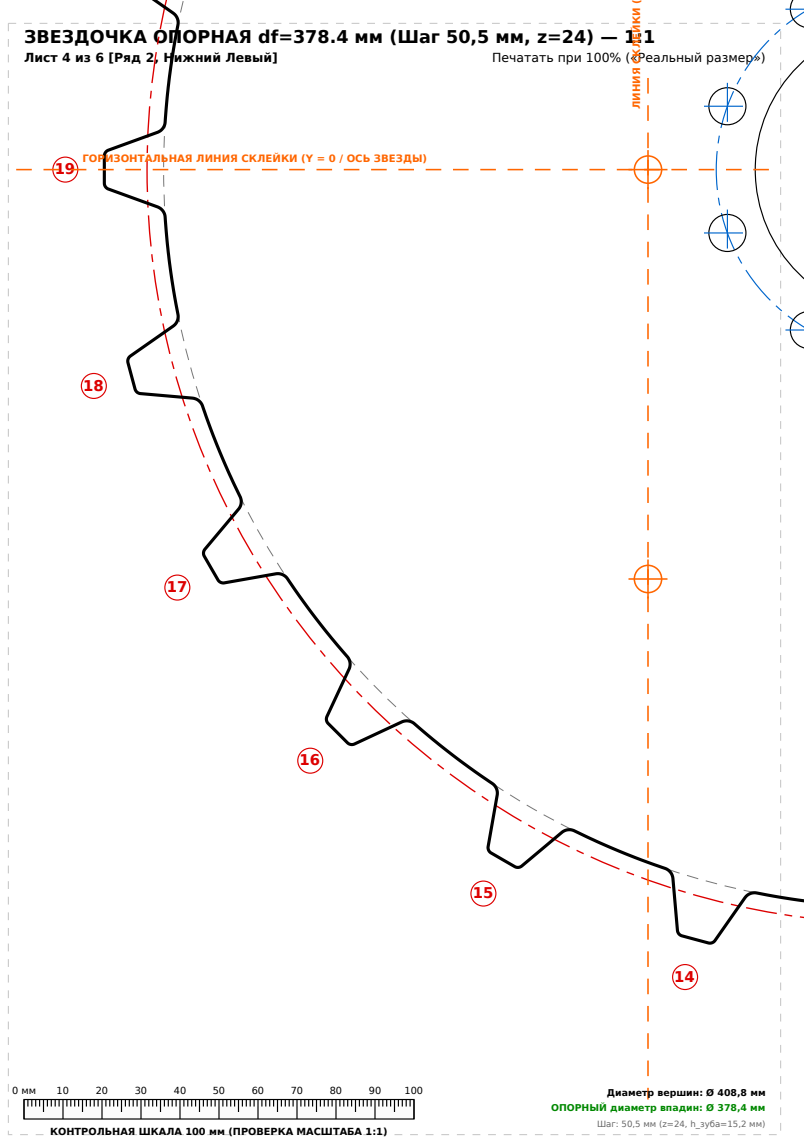
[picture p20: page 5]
ЛИНИЯ СКЛЕЙКИ (

ГОРИЗОНТАЛЬНАЯ ЛИНИЯ СКЛЕЙКИ (Y = 0 / ОСЬ ЗВЕЗДЫ)

Лист 5 из 6 [Ряд 2, Нижний Центр] | Печатать при 100% («Реальный размер»)

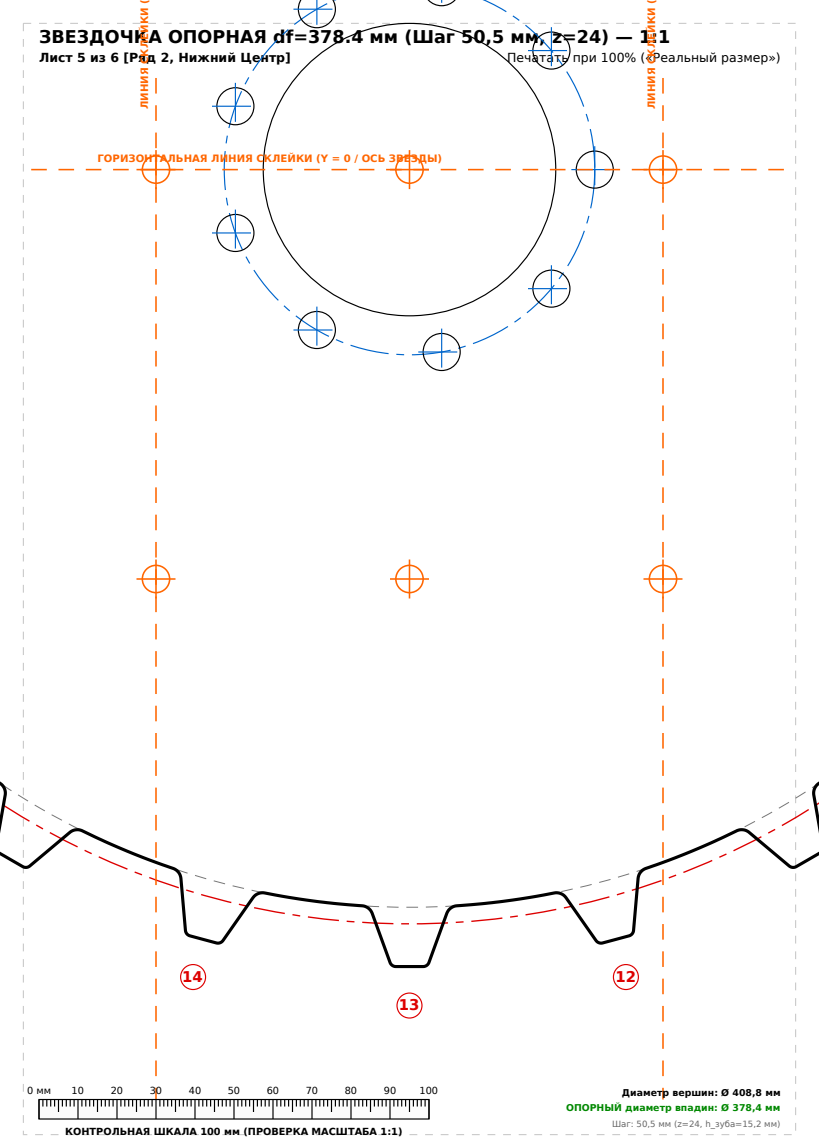
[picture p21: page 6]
ЛИНИЯ СКЛЕЙКИ (

ГОРИЗОНТАЛЬНАЯ ЛИНИЯ СКЛЕЙКИ (Y = 0 / ОСЬ ЗВЕЗДЫ)

Лист 6 из 6 [Ряд 2, Нижний Правый] | Печатать при 100% («Реальный размер»)

7

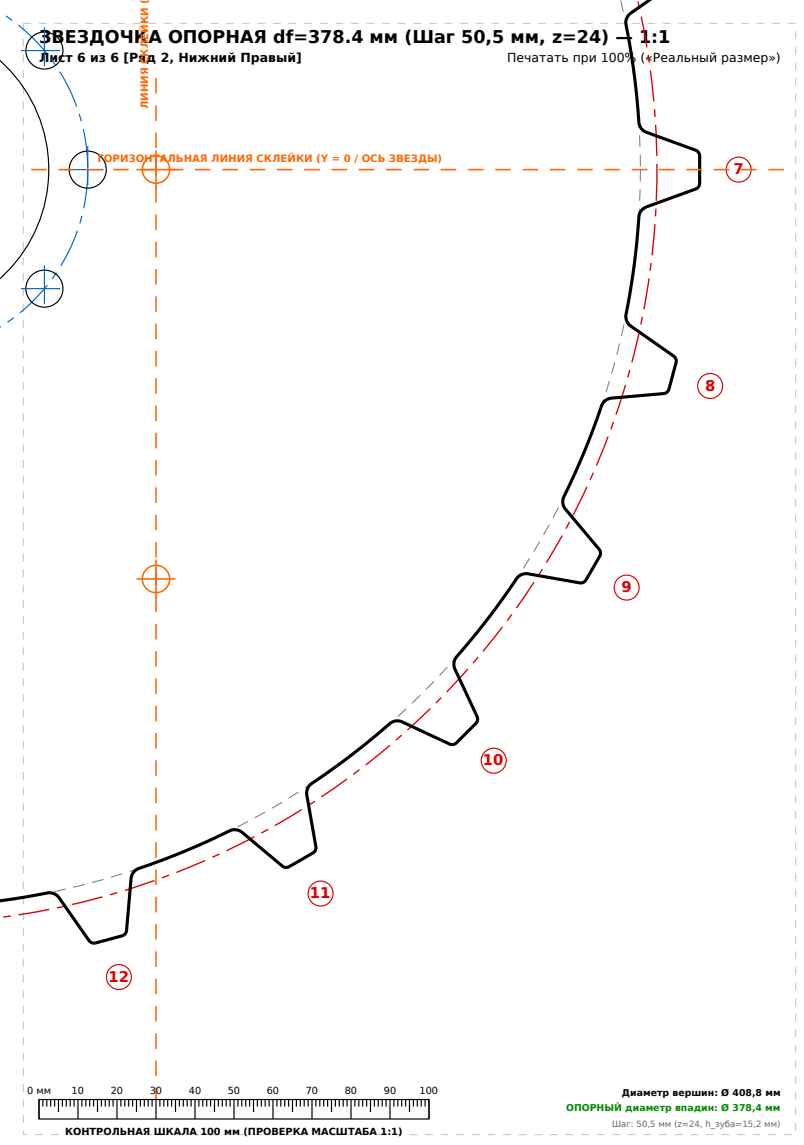
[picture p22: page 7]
ЛИНИЯ СКЛЕЙКИ (

ГОРИЗОНТАЛЬНАЯ ЛИНИЯ СКЛЕЙКИ (Y = 0 / ОСЬ ЗВЕЗДЫ)

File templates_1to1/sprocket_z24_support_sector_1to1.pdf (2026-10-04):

# ШАБЛОН-СЕКТОР ЗВЕЗДЫ С ОПОРНЫМ ДНОМ df=378.4 мм — 1:1

Скоба гусеницы «Муравей» садится прямо на дно впадины (6 поворотов на 60° вокруг центра Ø75)

ЦЕНТР ЗВЕЗДЫ (0,0); ЛУЧ 60° (ЛИНИЯ ПОВОРОТА); ЛУЧ 60°; Масштаб 1:1 (100%)

ОСОБЕННОСТЬ ЗВЕЗДЫ С ОПОРНЫМ ДНОМ (df = 378.4 мм):
• Высота зуба составляет 15.2 мм (вершина выступает сквозь окно гусеницы на 7.0 мм).
• Скоба гусеницы ложится прямо на дно впадины без зазора — колесо несет вес техники.
• Разметка: закрепить центр (0,0), обвести 4 зуба, повернуть на 60°, повторить 6 раз (всего 24 зуба).
• Материал: листовой СВМПЭ / капролон / фанера / сталь толщиной 10 мм.

КОНТРОЛЬНАЯ ШКАЛА 100 мм (ПРОВЕРКА МАСШТАБА 1:1)
